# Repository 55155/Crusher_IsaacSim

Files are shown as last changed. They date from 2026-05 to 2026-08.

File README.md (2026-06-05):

# Crusher_IsaacSim

**약품 분쇄기(Crusher)** 의 Isaac Sim → MuJoCo 마이그레이션 및 정제(Tablet) 형상 시뮬레이션 통합 저장소입니다.

---

## 목차

1. [프로젝트 개요](#프로젝트-개요)
2. [하드웨어 사양](#하드웨어-사양)
3. [디렉토리 구조](#디렉토리-구조)
4. [빠른 시작](#빠른-시작)
5. [GUI 실행 (tablet_sim_gui.py)](#gui-실행-tablet_sim_guipy)
6. [밀도 기반 접촉 경도 모델](#밀도-기반-접촉-경도-모델)
7. [CLI 레퍼런스](#cli-레퍼런스)
8. [변경 이력](#변경-이력)
9. [의존성 설치](#의존성-설치)
10. [주의 사항](#주의-사항)

> **✅ 2026-06-05 업데이트 (최신)** — **실제 모터 스펙(BL4281 + 1:212) 반영** 및 **준정적 조건** 구현: 환산 관성 주입으로 수치 안정성 확보, 실측 슬라이더 힘(600–650 N) 재현.  
> **✅ 2026-06-01 업데이트** — **GUI 프론트엔드** 추가 (`tablet_sim_gui.py`): 알약 무게·형상 입력 → 밀도·solref 실시간 계산, 경도 게이지 시각화, 단일/배치 시뮬 실행 원클릭 지원.  
> **✅ 2026-05-29 업데이트** — **밀도 기반 접촉 경도 모델** 추가 (`--density` / `--mass`): Hertzian Contact Theory를 기반으로 알약 밀도 → solref 시정수 τ 자동 계산.  
> → [하드웨어 사양 바로가기](#하드웨어-사양) | [GUI 실행 바로가기](#gui-실행-tablet_sim_guipy) | [밀도 기반 접촉 경도 상세 설명](#밀도-기반-접촉-경도-모델)

---

## 프로젝트 개요

| 구성 요소 | 설명 |
|---|---|
| **Crusher_IsaacSim_description** | ROS URDF + Isaac Sim USD 원본 기술 파일 |
| **MuJoCo_PlayGround** | Crusher 모델을 MuJoCo(MJCF)로 변환·시뮬레이션 |
| **tablets_stl** | 경구정(Tablet) 형상 파라미터 기반 STL 생성·시각화·충돌 분해 |

---

## 하드웨어 사양

### 구동 모터 (Motor 1 — Crusher 크랭크)

| 항목 | 사양 |
|---|---|
| 모터 모델 | **BL4281** (BLDC) |
| 정격 토크 | 0.185 N·m |
| 무부하 속도 | 5,800 RPM |
| 로터 관성 | 72 g·cm²  (= 7.2 × 10⁻⁶ kg·m²) |
| 감속기 감속비 | **1 : 212** |
| 크랭크 출력 stall 토크 | ≈ **12.5 N·m**  (효율 ~32%) |
| 크랭크 무부하 속도 | ≈ **27.4 RPM**  (= 2.87 rad/s) |
| 크랭크 환산 관성 J_refl | **0.324 kg·m²**  (= J_motor × 212²) |

> 고감속비 감속기는 역구동 차단(self-locking) 특성이 있어 슬라이더에 부하가 걸려도 크랭크 위치가 유지됩니다.

---

### 크랭크-슬라이더 기구

| 항목 | 값 |
|---|----|
| 크랭크 반경 `r` | **20 mm** |
| 커넥팅 로드 길이 `L` | **80 mm** |
| 운전 속도 | 8 RPM |
| 슬라이더 최대 힘 (실측) | **600 – 650 N** |

슬라이더 힘 공식 (크랭크 각도 θ 기준):

```
F_slider = τ_crank / (r × sin θ)

θ = 90°  →  F = 12.5 / 0.02       = 625 N   ← 실측값과 일치 ✓
θ = 60°  →  F = 12.5 / 0.01732    = 722 N
θ = 30°  →  F = 12.5 / 0.01       = 1250 N  ← TDP 근처 증폭
```

---

### 시뮬레이션 모터 파라미터 (`crusher_velocity_ctrl.py`)

| 파라미터 | 값 | 의미 |
|---|----|---|
| `MOTOR_STALL_TORQ` | `0.185` N·m | BL4281 모터 정격 토크 |
| `MOTOR_NOLOAD_RPM` | `5800` RPM | 무부하 속도 |
| `MOTOR_INERTIA_KG` | `72e-7` kg·m² | 로터 관성 |
| `GEAR_RATIO` | `212` | 감속비 |
| `CRANK_R_M` | `0.020` m | 크랭크 반경 |
| `ROD_L_M` | `0.080` m | 커넥팅 로드 길이 |
| `_TAU_STALL_CRANK` | `12.5` N·m | 크랭크 출력 stall 토크 (실측 역산) |
| `_J_REFL` | `0.3236` kg·m² | 크랭크 body 환산 관성 (J × n²) |
| `MOTOR_FORCELIM` | `12.5` N·m | velocity actuator forcerange 상한 |
| `VEL_KV_DEFAULT` | `≈ 14.9` N·m·s/rad | actuator 게인 (= τ_stall / ω_target) |

**준정적 안정 조건 검증:**

```
안정 지수 = kv × dt / J_eff

환산관성 미적용:  14.9 × 0.002 / 4.2e-5 ≈ 710  >> 2  →  수치 발산 ✗
환산관성 적용:    14.9 × 0.002 / 0.324  ≈ 0.09 << 2  →  안정 ✓
```

환산 관성은 `_build_model()` 내에서 `L4_Shaft_1` body의 `diaginertia`에 `_J_REFL`을 더하는 방식으로 주입됩니다.

---

## 디렉토리 구조

```
Crusher_IsaacSim/
│
├── README.md                          ← 이 파일
├── requirements.txt                   ← Python 의존성 목록
├── .gitignore                         ← STL 바이너리 제외 설정
│
├── Crusher_IsaacSim_description/      ← ROS 패키지 원본
│   ├── urdf/                          ← URDF / xacro / USD 파일
│   ├── meshes/                        ← 부품별 STL 메시
│   └── Code/                          ← 보조 스크립트 (질량/관성 검사, 재질 등)
│
├── CODES/                             ← 초기 Isaac Sim 디버그 스크립트 모음
│
├── 20260505/ ~ 20260513/              ← 날짜별 Isaac Sim 작업 스크립트
│
├── MuJoCo_PlayGround/                 ← MuJoCo 시뮬레이션 작업 공간
│   ├── MJCF/
│   │   ├── Crusher_IsaacSim.xml       ← 기본 MJCF (색상 없음)
│   │   ├── Crusher_IsaacSim_colored.xml  ← 색상 + Ground + 폐루프 제약 완성본
│   │   ├── Ground.stl                 ← 바닥 메시
│   │   └── L*.stl / base_link.stl    ← 부품 메시 (42개)
│   │
│   ├── 20260514/  view_mjcf.py        ← 초기 MJCF 로더
│   ├── 20260515/  open_crusher.py     ← 기본 XML 뷰어 (경고 억제 포함)
│   ├── 20260518/                      ← 색상 파이프라인 스크립트
│   │   ├── apply_csv_to_mjcf.py       ← mesh_colors.csv → MJCF material 적용
│   │   ├── extract_materials.py       ← USD에서 재질 추출
│   │   ├── make_mesh_csv.py           ← 메시-색상 CSV 생성
│   │   └── fusion360/                 ← Fusion 360 appearances.json 기반 적용
│   │
│   ├── 20260520/
│   │   └── open_crusher_colored.py   ← ★ 색상+Ground XML Python 뷰어 (신규)
│   │
│   ├── 20260527/
│   │   └── crusher_tablet_sim.py     ← ★ Crusher + Tablet 통합 시뮬레이션 (2-Phase)
│   │
│   ├── mujoco.bat                     ← ★ 더블클릭으로 뷰어 실행 (상대경로 수정)
│   └── convert_urdf_to_mjcf.py        ← URDF → MJCF 변환기
│
└── tablets_stl/                       ← 정제 형상 도구 모음
    ├── stl/
    │   ├── _tablet_index.csv          ← 1000개 정제 파라미터 메타데이터
    │   └── tablet_R*.stl              ← 생성된 STL 파일 (git 제외)
    │
    └── Codes/
        ├── viewer_desktop.py          ← ★ PyVista 3-슬라이더 형상 뷰어 + MuJoCo 연동
        ├── launch_mujoco.py           ← ★ STL → MuJoCo 물리 시뮬레이션 런처
        ├── collision_viewer.py        ← ★ 볼록 분해 4-모드 충돌 뷰어
        ├── tablet_generator.py        ← Fusion 360 AddIn (로컬 실행 불가, 참조용)
        ├── viewer.html                ← 웹 기반 STL 브라우저
        ├── start_viewer.bat           ← viewer_desktop.py 실행 배치
        ├── run_collision_viewer.bat   ← collision_viewer.py 실행 배치
        └── install_and_run.bat        ← 의존성 설치 + 뷰어 실행 배치
```

---

## 빠른 시작

### 1. Crusher MuJoCo 뷰어 실행

```bash
# 방법 A — 더블클릭 (권장)
MuJoCo_PlayGround/mujoco.bat

# 방법 B — Python 스크립트
conda activate isaac_sim
python MuJoCo_PlayGround/20260520/open_crusher_colored.py
```

> `mujoco.bat`은 `.py` 파일을 경유하지 않고 `python -m mujoco.viewer --mjcf` 명령으로  
> 설치된 MuJoCo 패키지의 CLI 뷰어를 **직접** 실행합니다.

### 2. 정제 형상 뷰어 실행

```bash
conda activate isaac_sim
python tablets_stl/Codes/viewer_desktop.py
```

- 슬라이더로 `R` / `AR` / `CV` 파라미터 조정 → 형상 실시간 미리보기
- **[MuJoCo에서 열기]** 버튼 → 선택한 STL을 별도 창에서 물리 시뮬레이션

### 3. 충돌 메시 분해 뷰어 실행

```bash
conda activate isaac_sim
python tablets_stl/Codes/collision_viewer.py
```

- 4가지 보기 모드: 원본 메시 / 볼록 껍질 / 겹침 보기 / 면 법선
- 거친(8) / 표준(16) / 정밀(32) / 최정밀(64) hull 프리셋

### 5. Crusher + Tablet 통합 시뮬레이션 실행

```bash
conda activate isaac_sim

# 기본 실행 (밀도 1200 kg/m³ 기본값)
python MuJoCo_PlayGround/20260527/crusher_tablet_sim.py <tablet.stl>

# 밀도 직접 지정 (경질 알약)
python MuJoCo_PlayGround/20260527/crusher_tablet_sim.py <tablet.stl> --density 1500

# 실측 질량으로 밀도 자동 계산
python MuJoCo_PlayGround/20260527/crusher_tablet_sim.py <tablet.stl> --mass 320

# 파일 선택 다이얼로그로 실행
python MuJoCo_PlayGround/20260527/crusher_tablet_sim.py
```

#### 배치 시뮬레이션 실행

```bash
# 순차 실행 (기본 밀도)
python MuJoCo_PlayGround/20260527/batch_tablet_sim.py

# 병렬 실행 + 경질 알약 설정
python MuJoCo_PlayGround/20260527/batch_tablet_sim.py --parallel --workers 8 --density 1500

# 빠른 테스트 (10개, plot 저장)
python MuJoCo_PlayGround/20260527/batch_tablet_sim.py --limit 10 --save-plots --density 1200
```

#### 동작 방식

| 단계 | 내용 |
|---|---|
| **Phase 1** (뷰어 없음, 500 스텝) | `lock_crank` equality 활성 (−90° 고정) → Crusher 메커니즘 안정화 |
| **Phase 2 — 대기** (0 ~ 3 s) | 뷰어 오픈, 모터 OFF. 알약은 mocap body로 충돌판 벽면에 고정 |
| **Phase 2 — 압축** (3 s ~) | `lock_crank` 해제 → Motor CCW −0.5 N·m 구동 → 슬라이더 전진, 법선 반력 측정 |
| **Phase 2 — 역전** (stall 감지) | 크랭크 각속도 \|ω\| < 0.05 rad/s 가 STALL_TIME_S(2.0s) 연속 → 방향 전환 (CCW↔CW 반복) |

#### 핵심 구조

- **XML 파일 없음** — `Crusher_IsaacSim_colored.xml` 을 메모리에서 파싱, Tablet body 노드를 동적 삽입 후 `MjModel.from_xml_string()` 으로 직접 로드
- **알약 고정 방식 — mocap body** — `mocap="true"` 선언으로 MuJoCo가 알약을 불가침 강체 벽으로 인식. `data.mocap_pos / mocap_quat` 으로 위치·자세 제어. 관통 없음
- **접촉력 측정** — `data.contact` + `mj_contactForce()` → contact frame → world frame 변환. 알약에 작용하는 법선 반력(F_Y) 수집
- **크랭크 제어** — `lock_crank` equality (polycoef=−π/2) 런타임 해제 (`data.eq_active`), **moving-window stall 감지** 기반 양방향 자동 역전
- **알약 자세** — X축 90° + Y축 90° 합성 쿼터니언 `[0.5, 0.5, 0.5, −0.5]` → 장축이 수직(world-Z) 방향
- **실시간 플롯** — `plt.ion()` 기반 실시간 F_Y 창이 시뮬레이터와 동시 업데이트 (20 step 마다)
- **출력** — 위치·힘·임펄스·각속도 그래프 5종을 PNG로 저장

#### 알약 배치 좌표 (MuJoCo world frame)

| 축 | 값 | 의미 |
|----|----|---|
| X | −47.879 mm | 충돌판 중심 정렬 |
| Y | 336.199 mm | 충돌판(back wall) 면에 밀착 |
| Z | 50.108 mm | 수직 높이 |

---

## GUI 실행 (tablet_sim_gui.py)

> 커맨드라인 없이 마우스로 모든 파라미터를 입력하고 시뮬레이션을 실행할 수 있는 tkinter 기반 GUI입니다.

### 실행

```bash
conda activate isaac_sim
python MuJoCo_PlayGround/20260527/tablet_sim_gui.py

# STL 파일을 미리 지정하고 열기
python MuJoCo_PlayGround/20260527/tablet_sim_gui.py --stl tablets_stl/stl/tablet_R8.0_AR0.80_CV0.25.stl
```

### GUI 화면 구성

```
┌────────────────────────────────────────────────────────────────┐
│  ⚗ Crusher Tablet Simulator  —  밀도 기반 접촉 경도 자동 계산  │
├──────────────────────────────┬─────────────────────────────────┤
│  📋 알약 물성 입력            │  📊 계산 결과 (실시간)           │
│                              │                                 │
│  ○ 무게(mg) 입력             │  추정 부피   [ 320.5 ] mm³      │
│  ● 밀도(kg/m³) 직접 입력     │  추정 밀도   [  1200 ] kg/m³    │
│                              │  solref τ   [ 0.0080] s        │
│  무게    [ 500  ] mg         │  solimp d   [ 0.991 ]          │
│  밀도    [1200  ] kg/m³      │                                 │
│                              │  ─────────────────────────      │
│  반지름 R [ 8.0 ] mm         │  경도: ████████░░  Hard 65%    │
│  종횡비 AR[ 0.80]            │                                 │
│  왕관비 CV[ 0.25]            │  밀도→τ 참조표                  │
│                              │   900 → 0.0200  연질            │
│  STL 파일 [___path___] [📂]  │  1200 → 0.0080  기본값 ◀현재   │
│                              │  1800 → 0.0020  경질            │
├──────────────────────────────┴─────────────────────────────────┤
│  🚀 단일 시뮬레이션 │  📦 배치 시뮬레이션                       │
│  [☐ 그래프 저장]  [  ▶ 시뮬레이션 실행  ]                      │
├────────────────────────────────────────────────────────────────┤
│  📟 출력                                                        │
│  $ python crusher_tablet_sim.py tablet.stl --density 1200      │
│  ◆ Phase 1: 500 스텝 안정화...                                  │
│  ✔ Phase 1 완료                                                 │
└────────────────────────────────────────────────────────────────┘
```

### 주요 기능

| 기능 | 설명 |
|---|---|
| **입력 모드 토글** | 무게(mg) 입력 ↔ 밀도(kg/m³) 직접 입력 선택 |
| **실시간 계산** | 숫자 입력 즉시 → 부피·밀도·τ·solimp 자동 갱신 |
| **경도 게이지** | Soft(녹) → Medium(노) → Hard(주) → Very Hard(빨) 색상 표시 |
| **참조 테이블** | 현재 밀도에 가장 가까운 행 자동 하이라이트 |
| **콘솔 출력** | 서브프로세스 stdout 실시간 표시 (오류=빨강, 완료=녹색) |
| **단일 탭** | STL + 밀도 → `crusher_tablet_sim.py` 실행 |
| **배치 탭** | STL 폴더 전체 + 병렬/순차 선택 → `batch_tablet_sim.py` 실행 |

### 입력 모드별 동작

**무게 입력 모드** (`무게(mg) 입력` 선택)
- 무게(mg) + 형상 파라미터(R, AR, CV) → 부피 추정 → 밀도 자동 계산
- 측정된 실측 질량이 있을 때 사용
- 파일명에 `R`, `AR`, `CV` 파라미터가 포함된 STL과 연동

**밀도 직접 입력 모드** (`밀도(kg/m³) 직접 입력` 선택)
- 밀도(kg/m³)를 직접 입력 → τ 즉시 계산
- 배치 시뮬레이션에서 동일 밀도를 전체 적용할 때 사용
- 참고: 연질 ≈ 900, 일반 ≈ 1200, 경질 ≈ 1800 (kg/m³)

---

## CLI 레퍼런스

### `crusher_tablet_sim.py` — 단일 알약 인터랙티브 시뮬레이션

```
python MuJoCo_PlayGround/20260527/crusher_tablet_sim.py [STL] [옵션]
```

| 인자 | 타입 | 기본값 | 설명 |
|---|---|---|---|
| `stl` | `str` (위치 인자) | 없음 → 파일 다이얼로그 | Tablet STL 파일 경로 |
| `--density KG_M3` | `float` | `1200.0` | 알약 밀도 \[kg/m³\] → solref τ 자동 계산 |
| `--mass MG` | `float` | — | 실측 질량 \[mg\] → 형상 파라미터로 밀도 자동 계산 |

> `--density`와 `--mass`는 **상호 배타**입니다. 둘 다 생략하면 기본 밀도 1200 kg/m³ 적용.

#### 사용 예시

```bash
# 1. STL 경로 직접 지정 (기본 밀도)
python MuJoCo_PlayGround/20260527/crusher_tablet_sim.py \
    tablets_stl/stl/tablet_R6.0_AR1.50_CV0.20.stl

# 2. 밀도 직접 지정 — 경질 알약 (탄산칼슘 계열)
python MuJoCo_PlayGround/20260527/crusher_tablet_sim.py \
    tablets_stl/stl/tablet_R6.0_AR1.50_CV0.20.stl \
    --density 1600

# 3. 실측 질량으로 밀도 자동 계산 — 320 mg 알약
python MuJoCo_PlayGround/20260527/crusher_tablet_sim.py \
    tablets_stl/stl/tablet_R6.0_AR1.50_CV0.20.stl \
    --mass 320

# 4. STL 생략 → GUI 파일 선택 다이얼로그 열림
python MuJoCo_PlayGround/20260527/crusher_tablet_sim.py
python MuJoCo_PlayGround/20260527/crusher_tablet_sim.py --density 1400
```

#### 출력 파일 (자동 저장)

```
MuJoCo_PlayGround/Sim_result/
├── csv/
│   └── {stem}__{YYYYMMDD_HHMMSS}.csv          ← 반력 프로파일 + 메타데이터
└── plot/
    ├── {stem}__{ts}__realtime_force.png        ← 실시간 F_Y 스냅샷
    ├── {stem}__{ts}__position.png              ← Slider/Tablet Y + Gap
    ├── {stem}__{ts}__force_magnitude.png       ← F_Y + 누적 임펄스
    ├── {stem}__{ts}__force_components.png      ← F_X / F_Y / F_Z
    └── {stem}__{ts}__crank_velocity.png        ← 크랭크 각속도 ω
```

---

### `batch_tablet_sim.py` — 다수 알약 헤드리스 배치 시뮬레이션

```
python MuJoCo_PlayGround/20260527/batch_tablet_sim.py [옵션]
```

| 인자 | 타입 | 기본값 | 설명 |
|---|---|---|---|
| `--stl-dir PATH` | `str` | `tablets_stl/stl` | STL 파일 디렉토리 |
| `--duration SEC` | `float` | `10.0` | 정제 1개당 시뮬레이션 시간 \[s\] |
| `--density KG_M3` | `float` | `1200.0` | 알약 밀도 \[kg/m³\] → 전체 배치에 일괄 적용 |
| `--parallel` | flag | `False` | `multiprocessing.Pool` 병렬 실행 활성화 |
| `--workers N` | `int` | `os.cpu_count()` | 병렬 워커 수 (`--parallel` 사용 시) |
| `--save-plots` | flag | `False` | 정제별 개별 플롯 PNG 저장 (느림, 디스크 사용 많음) |
| `--limit N` | `int` | 없음 (전체) | 처리할 STL 수 제한 (테스트·디버그용) |

#### 사용 예시

```bash
# 1. 기본 순차 실행 — 전체 STL, 10s/tablet, 기본 밀도
python MuJoCo_PlayGround/20260527/batch_tablet_sim.py

# 2. 병렬 실행 — 8 워커, 경질 알약
python MuJoCo_PlayGround/20260527/batch_tablet_sim.py \
    --parallel --workers 8 \
    --density 1500

# 3. 긴 시뮬레이션 — 30s/tablet, 연질 알약
python MuJoCo_PlayGround/20260527/batch_tablet_sim.py \
    --duration 30 \
    --density 950

# 4. 빠른 테스트 — 10개만, plot 저장
python MuJoCo_PlayGround/20260527/batch_tablet_sim.py \
    --limit 10 --save-plots \
    --density 1200

# 5. 커스텀 STL 디렉토리
python MuJoCo_PlayGround/20260527/batch_tablet_sim.py \
    --stl-dir /path/to/custom_stl \
    --parallel --workers 4 \
    --density 1300
```

#### 출력 파일 (자동 저장)

```
MuJoCo_PlayGround/Sim_result/
├── csv/
│   ├── {YYYYMMDD_HHMMSS}/
│   │   ├── tablet_R6.0_AR1.50_CV0.20.csv      ← 개별 반력 프로파일
│   │   └── ...                                 ← (STL 1개당 CSV 1개)
│   └── summary__{YYYYMMDD_HHMMSS}.csv          ← 배치 요약 (행=1정제)
└── plot/
    ├── {YYYYMMDD_HHMMSS}/
    │   ├── tablet_R6.0_AR1.50_CV0.20__force.png ← 개별 플롯 (--save-plots 시)
    │   └── ...
    └── summary__{YYYYMMDD_HHMMSS}.png           ← 4패널 요약 산포도
```

#### summary CSV 컬럼

| 컬럼 | 설명 |
|---|---|
| `stem` | STL 파일명 (확장자 제외) |
| `R_mm`, `AR`, `CV` | 형상 파라미터 |
| `density_kg_m3` | 사용된 밀도 |
| `solref_tau_s` | 계산된 solref τ |
| `F_Y_max_N` | 최대 법선 반력 \[N\] |
| `F_Y_min_N` | 최소 법선 반력 \[N\] |
| `F_mag_max_N` | 최대 합력 크기 \[N\] |
| `Impulse_J_Y_Ns` | 누적 임펄스 J_Y \[N·s\] |
| `first_contact_s` | 첫 접촉 발생 시각 \[s\] |
| `direction_changes` | 크랭크 방향 전환 횟수 |
| `n_steps` | 수집된 스텝 수 |
| `wall_time_s` | 실제 소요 시간 \[s\] |
| `error` | 오류 메시지 (정상 시 공백) |

---

### 주요 상수 (코드 상단에서 직접 수정)

아래 상수는 CLI 인자 없이 코드에서 직접 조정합니다.

#### `crusher_tablet_sim.py`

| 상수 | 기본값 | 설명 |
|---|---|---|
| `SIM_DURATION` | `30.0` s | Phase 2 측정 시간 |
| `MOTOR_CTRL` | `-0.5` N·m | 크랭크 모터 토크 (음수=CCW) |
| `MOTOR_DELAY` | `3.0` s | 모터 구동 지연 시간 |
| `STALL_TIME_S` | `2.0` s | stall 판정 유지 시간 ("지긋이 누르는" 시간) |
| `STALL_VEL_THR` | `0.05` rad/s | stall 판정 속도 임계값 |
| `RT_PLOT_INTERVAL` | `20` steps | 실시간 플롯 갱신 주기 |
| `DENSITY_REF_SOFT` | `900` kg/m³ | solref 매핑 연질 기준점 |
| `DENSITY_REF_HARD` | `1800` kg/m³ | solref 매핑 경질 기준점 |
| `SOLREF_TAU_SOFT` | `0.020` s | 연질 기준 τ (MuJoCo 기본값) |
| `SOLREF_TAU_HARD` | `0.002` s | 경질 기준 τ (실용적 최솟값) |

#### `batch_tablet_sim.py` (추가)

| 상수 | 기본값 | 설명 |
|---|---|---|
| `PHASE1_STEPS` | `500` steps | 메커니즘 안정화 스텝 수 |

---

## 밀도 기반 접촉 경도 모델

### 개요

같은 형상(Shape)의 알약이라도 **밀도(density)**가 높을수록 파쇄가 어렵습니다.  
밀도는 실측 무게와 형상(부피)으로 추정할 수 있으며, 이를 MuJoCo 접촉 파라미터(`solref`)에 반영합니다.

### 이론적 근거 (Hertzian Contact Theory)

```
제약공학 사실:
  압착 압력↑  →  밀도(ρ)↑  →  Young's modulus(E)↑  →  경도↑

Hertzian Contact:
  접촉 강성  K_contact  ∝  E*  (등가 탄성계수)
  경험적 관계: E  ∝  ρⁿ   (n ≈ 2~3)

MuJoCo solref 연결:
  K_mujoco  ∝  1/τ²   (τ = solref 시정수)
  K ∝ ρⁿ, K ∝ 1/τ²   →   τ  ∝  ρ^(-n/2)

결론: 밀도 높음 → τ 작음 → 접촉 강성 높음 → 관통 감소
```

### 매핑 함수

두 기준점을 지정하면 **power-law**로 보간합니다:

```
τ(ρ) = τ_soft × (ρ_soft / ρ)^α

        log(τ_hard / τ_soft)
α  = ─────────────────────────  ≈ −3.32
        log(ρ_hard / ρ_soft)
```

| 밀도 (kg/m³) | τ (s) | 상대 강성 (1/τ²) | 대표 알약 |
|---|---|---|---|
| 900 | 0.0200 | 1× | 연질 (저압착 포도당) |
| 1100 | 0.0096 | 4.3× | 표준 하한 |
| **1200** | **0.0080** | **6.3×** | ← 기본값 |
| 1400 | 0.0053 | 14× | 표준 경질 |
| 1600 | 0.0033 | 37× | 고압착 |
| 1800 | 0.0020 | 100× | 초경질 (탄산칼슘) |

### 부피 추정 및 밀도 계산

알약 실측 질량(mg)만 알면 형상 파라미터로 밀도를 자동 계산합니다:

```
V_ellipsoid = (4/3)π × (R×AR) × R × (th/2)
V_biconvex  = V_ellipsoid × 0.82   (biconvex 보정계수)

ρ = mass / V_biconvex
```

```bash
# 실측 질량 320mg → 밀도 자동 계산 → τ 자동 설정
python crusher_tablet_sim.py tablet_R6.0_AR1.50_CV0.20.stl --mass 320
```

### 구현 위치

| 함수 | 설명 |
|---|---|
| `estimate_tablet_volume_mm3(R_mm, AR, CV)` | 형상 파라미터 → 부피 [mm³] 추정 |
| `mass_to_density(mass_mg, R_mm, AR, CV)` | 질량 + 형상 → 밀도 [kg/m³] |
| `density_to_solref_tau(density_kg_m3)` | 밀도 → solref τ [s] (power-law) |
| `_build_model(..., density_kg_m3)` | geom에 `density`, `solref`, `solimp` 적용 |

### 조정 가능한 기준점 (코드 상단 상수)

```python
DENSITY_REF_SOFT  = 900.0    # kg/m³  연질 기준점
DENSITY_REF_HARD  = 1800.0   # kg/m³  경질 기준점
SOLREF_TAU_SOFT   = 0.020    # s      연질 τ (MuJoCo 기본값)
SOLREF_TAU_HARD   = 0.002    # s      경질 τ (실용적 최솟값)
DENSITY_DEFAULT   = 1200.0   # kg/m³  미지정 시 기본값
BICONVEX_VOL_FACTOR = 0.82   # biconvex 부피 보정계수
```

### CSV 출력 컬럼 (신규 추가)

결과 CSV 메타데이터에 밀도 관련 정보가 자동 기록됩니다:

```
# density_kg_m3, vol_estimate_mm3, biconvex_factor
# solref_tau_s, solimp_dmax, DENSITY_REF_SOFT, DENSITY_REF_HARD
```

---

### 4. 정제 STL 생성 (Fusion 360 전용)

`tablets_stl/Codes/tablet_generator.py` 참조.  
로컬에서 직접 실행 불가 — Fusion 360 내부 AddIn으로만 사용 가능합니다.

---

## 변경 이력

### 2026-06-05 — 실제 모터 스펙 반영 및 준정적 조건 구현

#### 핵심 변경

| 항목 | 변경 전 | 변경 후 |
|---|---|---|
| **MOTOR_FORCELIM** | 120 N·m (임의값) | **12.5 N·m** (실측 역산: F=625N × r=0.02m) |
| **VEL_KV_DEFAULT** | 60 → 3 (진동 수정) | **14.9** (= τ_stall / ω_target, 물리 근거 수치) |
| **환산 관성 주입** | 없음 | `_build_model()`에서 `L4_Shaft_1`에 J×n²=**0.324 kg·m²** 추가 |
| **모터 상수 추가** | 없음 | `GEAR_RATIO`, `MOTOR_STALL_TORQ`, `MOTOR_INERTIA_KG`, `CRANK_R_M`, `ROD_L_M` |

#### 배경: 진동 원인 및 해결 과정

kv=60이었을 때 stall 토크 = 60 × 0.838 = **50 N·m** (현실 모터의 ~20배).  
접촉 순간 속도 강하 → kv × Δω 보정 토크 과다 → 속도 오버슈트 → 진동.

| 단계 | kv | MOTOR_FORCELIM | 안정 지수 kv·dt/J | 결과 |
|---|----|---|---|---|
| 초기 | 60 | 120 N·m | 710 (J≈크랭크만) | 진동 발생 |
| 1차 수정 | 3 | 3 N·m | 0.09 | 진동 해소, 힘 과소 |
| **최종** | **14.9** | **12.5 N·m** | **0.09** (환산관성 포함) | 안정 + 실측 재현 ✓ |

#### 슬라이더 힘 검증

실측 600–650 N ↔ 시뮬레이션 예측:
- τ_stall = 12.5 N·m, r = 0.02 m, θ = 90° → F = **625 N** ✓

#### 수정 파일

| 파일 | 수정 내용 |
|---|---|
| `MuJoCo_PlayGround/20260603/crusher_velocity_ctrl.py` | BL4281 스펙 상수 추가, 환산 관성 주입(`_build_model`), kv·forcelim 실측 재산정 |
| `README.md` | 하드웨어 사양 섹션 신규 추가 |

---

### 2026-05-29 (2) — 밀도 기반 접촉 경도 모델 (solref 자동 계산)

#### 핵심 변경

| 항목 | 변경 전 | 변경 후 |
|---|---|---|
| **tablet geom solref** | 미지정 (MuJoCo 기본값 τ=0.02s) | **밀도 → τ 자동 계산** (power-law 보간) |
| **tablet geom density** | 1200 kg/m³ 하드코딩 | `--density` 또는 `--mass` 인자로 동적 설정 |
| **_build_model 시그니처** | `(stl_path, R_mm, half_th)` | `(stl_path, R_mm, half_th, density_kg_m3)` |
| **CLI 인자** | 없음 | `--density KG_M3` / `--mass MG` (상호 배타) |
| **CSV 메타데이터** | 없음 | `density_kg_m3`, `solref_tau_s`, `solimp_dmax`, `vol_estimate_mm3` 추가 |
| **batch_tablet_sim.py** | 동일 | `--density` 인자 + task tuple에 밀도 포함 |

#### 신규 함수

| 함수 | 위치 | 설명 |
|---|---|---|
| `estimate_tablet_volume_mm3(R, AR, CV)` | 두 파일 공통 | 형상 파라미터 → biconvex 부피 [mm³] |
| `mass_to_density(mass_mg, R, AR, CV)` | 두 파일 공통 | 질량(mg) + 형상 → 밀도 [kg/m³] |
| `density_to_solref_tau(density_kg_m3)` | 두 파일 공통 | 밀도 → solref τ [s] (power-law) |

#### 이론

```
Hertzian Contact: E ∝ ρⁿ  →  K ∝ 1/τ²  →  τ ∝ ρ^(-n/2)
α = log(τ_hard/τ_soft) / log(ρ_hard/ρ_soft) ≈ −3.32
```

#### 수정 파일

| 파일 | 변경 내용 |
|---|---|
| `MuJoCo_PlayGround/20260527/crusher_tablet_sim.py` | v7 — 밀도 기반 solref, --density/--mass CLI |
| `MuJoCo_PlayGround/20260527/batch_tablet_sim.py` | v2 — 동일 로직, --density CLI, task tuple 확장 |
| `README.md` | 밀도 기반 접촉 경도 모델 섹션 신규 추가 |

---

### 2026-05-29 (1) — Moving-window 역전 알고리즘 + 실시간 반력 플롯

#### 핵심 변경

| 항목 | 변경 전 | 변경 후 |
|---|---|---|
| **크랭크 역전 방식** | 접촉력 임계(`\|F_Y\| > 5 N`) → CCW→CW 단방향, 복귀 없음 | **Moving-window stall 감지** — 양방향 (CCW↔CW 반복) |
| **역전 트리거 조건** | 접촉력 크기 기반 | 크랭크 각속도 `\|ω\| < 0.05 rad/s` 30 step 연속 유지 |
| **실시간 플롯** | 없음 (시뮬 종료 후 정적 PNG만) | `plt.ion()` 기반 F_Y 실시간 창 (20 step 간격 갱신) |
| **출력 그래프** | 3종 (위치, 힘, XYZ 성분) | **5종** — 위치, 힘+임펄스, XYZ 성분, **실시간 스냅샷**, **크랭크 각속도** |
| **콘솔 출력** | 위치·힘·접촉 수 | 위치·힘·각속도·현재 방향(`[CCW]`/`[CW]`) |

#### 상세 내용

**① Moving-window stall 감지 기반 양방향 역전**
```
STALL_WINDOW  = 30      # 연속 판정 스텝 수 (0.002 s × 30 = 0.06 s)
STALL_VEL_THR = 0.05    # 크랭크 속도 임계 [rad/s]
```
- `deque(maxlen=30)` — 최신 30 스텝의 `|ω| < threshold` 불리언 기록
- `all(stall_buf)` 가 True 되는 순간 `motor_dir = -motor_dir` 전환, deque 초기화
- 부호 규칙: `data.ctrl[act_crank] = motor_dir × MOTOR_CTRL`
  - `motor_dir = +1` (CCW) → ctrl = −0.5 N·m
  - `motor_dir = −1` (CW) → ctrl = +0.5 N·m
- CCW→CW, CW→CCW 모두 자동 처리. 역전 횟수·시각 콘솔 출력 및 플롯 마커 기록

**② 실시간 법선 반력 플롯 (`plt.ion()`)**
- 시뮬레이터 뷰어와 동시에 별도 창으로 F_Y [N] 실시간 표시
- 20 step(0.04 s)마다 `line_fy.set_data()` + `ax_rt.relim()` + `flush_events()`
- 방향 전환 이벤트 수직선(axvline)을 실시간 갱신
- 시뮬 종료 후 `crusher_tablet_realtime_force.png` 로 저장

**③ 크랭크 각속도 플롯 추가 (그림 4)**
- `data.qvel[crank_vadr]` 로그를 시간 축으로 표시
- stall 임계선 `±STALL_VEL_THR` 수평선 표시
- 방향 전환 이벤트 수직선 동기화

#### 수정 파일

| 파일 | 수정 내용 |
|---|---|
| `MuJoCo_PlayGround/20260527/crusher_tablet_sim.py` | v5 — moving-window 역전, 실시간 플롯, 각속도 플롯, 다중 역전 이벤트 추적 |

---

### 2026-05-28 — 알약 물리 고정 방식 전환 및 반력 측정 파이프라인 완성

#### 핵심 변경

| 항목 | 변경 전 | 변경 후 |
|---|---|---|
| **알약 고정 방식** | freejoint + 매 스텝 qpos/qvel 덮어쓰기 (kinematic hold) | `mocap="true"` body — 관통 없는 불가침 강체 벽 |
| **접촉력 측정** | `cfrc_ext` (부정확, 유령 body 문제) | `data.contact` + `mj_contactForce()` → world frame 변환 |
| **크랭크 초기 각도** | +90° | **−90°** |
| **모터 방향** | CW (+0.5 N·m) | **CCW (−0.5 N·m)**, 3초 지연 후 구동 |
| **크랭크 역전 트리거** | gap 기반 (슬라이더 위치) → 벽 접촉 시 고착으로 동작 안 됨 | **접촉력 기반** `|F_Y| > 5 N` → 신뢰성 있는 역전 |
| **알약 자세** | X축 90° (눕힘) | X축 90° + Y축 90° 합성 → **세로(수직) 방향** |

#### 상세 내용

**① mocap body 전환 (관통 문제 해결)**
- `freejoint` 방식에서는 MuJoCo contact solver가 분리 impulse를 계산해도 매 스텝 qpos를 덮어써서 슬라이더가 알약을 관통하는 문제 발생
- `mocap="true"` body는 물리 엔진이 직접 불가침 강체로 취급 → 슬라이더가 알약을 밀어내고 알약은 고정 유지
- 위치·자세 제어: `data.mocap_pos[mocap_id]`, `data.mocap_quat[mocap_id]`

**② lock_crank equality 런타임 토글**
- `Crusher_IsaacSim_colored.xml` 의 `lock_crank` (polycoef=−1.5708, solref=−100000) 로 Phase 1에서 크랭크를 −90°에 고정
- Phase 2 시작 3초 후 `data.eq_active[eq_lock_id] = 0` 으로 해제 → 모터 CCW 구동

**③ 접촉력 기반 크랭크 역전**
- 기존 gap 기반: 슬라이더가 mocap 벽에 막히면 gap이 최솟값에 고착 → `elif gap > min + 0.5mm` 조건 영원히 불충족
- **수정**: `|F_Y| > REVERSE_F_THRESHOLD (5 N)` 초과 시점에 `ctrl = +0.5 N·m` (CW) 역전
- 역전 시각, 접촉력, gap 값을 콘솔 출력 및 플롯 마커로 기록

**④ 법선 반력 플롯 개선**
- F_Y 그래프 레이블을 "Normal Contact Force (World-Y)" 로 명확화
- 모터 ON 시각, 크랭크 역전 시각을 수직선(axvline)으로 표시
- 압축(양)/인장(음) 구간 fill_between 색 구분

**⑤ Tablet Shape Viewer 단축키 패널 추가**
- `viewer_desktop.py` 좌측 패널 하단에 PyVista 단축키 섹션 추가
- 마우스 조작 / 렌더링(`W` 와이어프레임 ★) / 카메라 / 기타 4개 섹션

#### 수정 파일

| 파일 | 수정 내용 |
|---|---|
| `MuJoCo_PlayGround/20260527/crusher_tablet_sim.py` | mocap body, lock_crank 토글, CCW 모터, 역전 로직, 법선 반력 플롯 |
| `MuJoCo_PlayGround/MJCF/Crusher_IsaacSim_colored.xml` | lock_crank polycoef −1.5708 복원 |
| `tablets_stl/Codes/viewer_desktop.py` | PyVista 단축키 패널 추가 |

---

### 2026-05-27 — Crusher + Tablet 통합 시뮬레이션 완성

#### 신규 파일

| 파일 | 내용 |
|---|---|
| `MuJoCo_PlayGround/20260527/crusher_tablet_sim.py` | Crusher XML + Tablet STL을 메모리에서 조합해 2-Phase 통합 시뮬레이션 실행. Phase 1(메커니즘 안정화) → Phase 2(알약 고정 + 접촉력 측정 + 그래프 저장) |

#### 주요 변경 사항

| 항목 | 내용 |
|---|---|
| **알약 고정 방식** | freejoint(6자유도) + 매 스텝 kinematic hold (qpos/qvel 덮어쓰기) → 알약을 공간에 고정하면서 cfrc_ext 접촉 반력 측정 가능 |
| **알약 배치** | Y 좌표를 `WALL_Y_MM`(336.199 mm)으로 설정 — 충돌판 벽면에 중심 밀착 |
| **MJCF 구성** | 별도 XML 파일 없음 — 기존 Crusher XML을 메모리에서 파싱 후 Tablet body / sensor 노드 동적 삽입 |
| **뷰어 site 구 제거** | `sitegroup` 전체 `False` — 중심부 구 형태 gizmo 비표시 |

---

### 2026-05-26 — Crank-Slider 메커니즘 진단 및 좌표계 분석

#### 핵심 발견

| 항목 | 내용 |
|---|---|
| **Equality Constraint 타입 오류** | `connect`는 위치(3-DOF)만 구속 → L7-L8 사이 회전 자유도 미구속으로 진동 발생. `weld`(위치+방향 완전 고정)로 교체 필요 |
| **Constraint Gap 원인 분석** | anchor=0.027 설정 시 L8 body와 10 mm 갭 발생 → 제약력 500 N (중력 12.7 N의 **39배**) → CCW 비정상 회전 유발 |
| **크랭크 회전축 오해** | XML `axis="0 0 1"` (body local Z) + `quat="0.5 0.5 0.5 0.5"` → 실제 world 회전축 = **[1, 0, 0] (world X)**. 중력(-Z)과 수직이므로 최대 토크 발생 |
| **MuJoCo 좌표계 변환** | `quat="0.5 0.5 0.5 0.5"` → R=`[[0,0,1],[1,0,0],[0,1,0]]` : URDF X→MuJoCo Y, URDF Y→MuJoCo Z, URDF Z→MuJoCo X |

#### 신규 파일

| 파일 | 내용 |
|---|---|
| `MuJoCo_PlayGround/20260526/coordinate_gizmo.py` | MuJoCo 월드 좌표계(XYZ 기즈모) 확인 스크립트. 뷰어 원점에 body frame 표시 |
| `MuJoCo_PlayGround/20260526/open_urdf.py` | 원본 URDF를 MuJoCo로 직접 로드해 각 body 월드 위치·joint 목록 출력 및 뷰어 실행 |

#### MJCF 수정 이력 (Crusher_IsaacSim_colored.xml)

| 수정 | 내용 |
|---|---|
| L5-L6, L6-L7 hinge damping 추가 | `damping="0.5"` — 초기 불안정 진동 억제 |
| L8 slide joint damping 추가 | `damping="5"` |
| L8_Link3_Shaft_1 body pos 수정 | Rigid32 접합 위치 = `(-0.048302, 0.236278, 0.049431)` (URDF 실측 검증 완료) |
| Equality Constraint anchor | URDF Rigid32 joint xyz=(0.037, 0, -0.005) 기준. **다음 단계: connect → weld 교체 예정** |
| 뷰어 설정 | `mjVIS_CONVEXHULL=False`, `geomgroup[3]=False` — visual mesh 전용 표시 |

---

### 2026-05-21 — macOS 호환성 수정 및 tablet_generator Fusion 360 등록

| 파일 | 변경 내용 |
|---|---|
| `tablets_stl/Codes/viewer_desktop.py` | `subprocess.CREATE_NEW_CONSOLE` (Windows 전용) → `platform.system()` 감지 후 조건부 적용으로 macOS 호환 수정 |
| `tablets_stl/stl/_tablet_index.csv` | Fusion 360 `tablet_generator` AddIn 실행으로 정제 STL 1,000개 생성 및 인덱스 갱신 |

---

### 2026-05-20 — MuJoCo 통합 완성 및 구조 정리

#### MuJoCo_PlayGround

| 파일 | 변경 내용 |
|---|---|
| `mujoco.bat` | 하드코딩된 절대경로 → `%~dp0` 기반 상대경로로 전면 수정; conda 활성화 경로도 `%USERPROFILE%` 변수로 포터블화 |
| `20260520/open_crusher_colored.py` | **신규** — `Crusher_IsaacSim_colored.xml`(Ground.stl 포함)을 Python API(`mujoco.viewer.launch`)로 여는 스크립트; `__file__` 기준 상대경로 사용 |

#### tablets_stl

| 파일 | 변경 내용 |
|---|---|
| `Codes/viewer_desktop.py` | **[MuJoCo에서 열기]** 버튼 추가; STL 로드 성공 시 활성화, `subprocess.Popen`으로 비차단 실행 |
| `Codes/launch_mujoco.py` | **신규** — 선택된 STL을 메모리 내 MJCF로 변환(`from_xml_string + assets`), 물리 파라미터(밀도 1200 kg/m³, 마찰 0.5) 설정 후 뷰어 실행 |
| `Codes/launch_mujoco.py` | **버그 수정** — `_print_params()` 정규식이 파일명의 `.stl` 확장자까지 캡처하여 `float('0.20.')` 오류 발생 → `os.path.splitext()` 로 확장자 제거 후 정규식 적용 |
| `Codes/collision_viewer.py` | **신규** — 볼록 분해(CoACD → VHACD → single hull fallback) 독립 뷰어; 4-모드 시각화 |

#### 저장소 공통

| 파일 | 변경 내용 |
|---|---|
| `requirements.txt` | **신규** — 그룹별 의존성 정리 (수치연산 / 3D시각화 / 메시처리 / MuJoCo / JAX / 이미지처리); 비pip 패키지(Isaac Sim, Fusion 360, Blender) 설치 안내 주석 포함 |
| `.gitignore` | **신규** — `tablets_stl/stl/*.stl`, `tablets_stl/collision/*.stl` 바이너리 제외; Python 캐시 제외 |

---

### 2026-05-18 — Crusher 색상 파이프라인 완성

| 변경 내용 |
|-----------|
| Fusion 360 appearance JSON 추출 스크립트 (`extract_appearance.py`) |
| `mesh_colors.csv` 기반 MJCF material 자동 적용 (`apply_csv_to_mjcf.py`) — RGB 0-255 → 0-1 변환, 조명 3개 자동 추가 |
| `Crusher_IsaacSim_colored.xml` 완성 — 색상·조명·Ground.stl·Crank-slider 폐루프 equality constraint·Motor1_crank 액추에이터·L1_Slider_jig 프리즈매틱 조인트 포함 |

---

### 2026-05-15 — MuJoCo 초기 마이그레이션

| 변경 내용 |
|-----------|
| URDF → MJCF 변환 (`convert_urdf_to_mjcf.py`) |
| 기본 뷰어 스크립트 `20260515/open_crusher.py` (MuJoCo UserWarning 억제) |

---

### 2026-05-05 ~ 2026-05-13 — Isaac Sim 디버그 및 관절 설정

| 작업 |
|------|
| 구동부 관절(Drive, Prismatic, Mimic) 설정 및 진단 스크립트 |
| Rack-and-Pinion 기어 연결 디버그 |
| CoACD 충돌 메시 최적화 |
| 질량/관성 텐서 검사 및 수정 |

---

## 의존성 설치

```bash
conda activate isaac_sim
pip install -r requirements.txt
```

> ⚠️ 아래 패키지는 pip으로 설치되지 않습니다.
> - **Isaac Sim** (`omni.*`, `carb`, `pxr`) — NVIDIA Isaac Sim 설치 시 번들 제공
> - **Fusion 360 API** (`adsk`) — Autodesk Fusion 360 내부 실행 전용
> - **Blender Python** (`bpy`) — Blender 내부 실행 전용

---

## 주의 사항

- **STL 바이너리** (`tablets_stl/stl/*.stl`) 는 `.gitignore`에 의해 Git에서 제외됩니다.  
  STL 파일은 Fusion 360 AddIn(`tablet_generator.py`)으로 로컬에서 생성하세요.
- `tablet_generator.py`는 `adsk` 모듈 의존성으로 인해 **Fusion 360 외부에서 실행 불가**합니다.  
  파일 내 주석의 설치 경로 안내를 따르세요.
- MuJoCo STL 단위는 **mm → m 자동 변환** (scale `0.001`)이 적용됩니다.  
  Fusion 360 기본 STL 내보내기 단위가 mm이기 때문입니다.

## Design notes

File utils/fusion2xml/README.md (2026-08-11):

# fusion2xml — Fusion 360 → MuJoCo MJCF

Fusion 디자인을 MuJoCo `.xml`(MJCF)로 바로 내보내는 Add-In.

## 왜 fusion2urdf 로는 안 되나

URDF 에는 equality constraint 가 없다. 링크마다 부모가 **정확히 하나**인 트리만
표현할 수 있어서, 커넥팅로드-크랭크 같은 폐루프 기구는 원리적으로 담기지 않는다.
fusion2urdf 는 루프를 닫는 조인트를 URDF 에서 빼 사이드카 파일
(`*.constraints.mjcf`)에 좌표만 적어 두고, 사람이 MJCF 로 손으로 옮겨야 했다.

fusion2xml 은 처음부터 MJCF 를 쓴다. `<body>` 중첩은 여전히 트리지만, 루프를 닫는
조인트는 **같은 XML 안의 `<equality>`** 로 닫히므로 옮길 게 없다.

## ⚠ 내보내기 전에 — 모든 조인트를 0으로 되돌릴 것

**Fusion 조인트를 드래그해 둔 자세 그대로 내보내면 조인트 원점이 그 자세로
굳어 들어간다.** 메시는 별개로 배치되므로 기구 치수가 조용히 틀어진다.

실제로 겪은 사례(`docs/DigitalTwin.md` §12-3): 크랭크를 사점(180°)에 둔 채
내보냈더니 크랭크핀과 equality anchor가 **둘 다 정확히 35 mm(= 2×편심)**
밀렸다. 커넥팅로드의 유효 길이가 60 mm → 25 mm로 뭉개져 로드 요동폭이
33.9° → 89.1°가 됐고, 풀리와 로드가 반대로 도는 것처럼 보였다.

**행정(stroke) = 2 × 편심이라 편심 방향이 반대여도 행정은 같게 나온다.**
행정만 확인하면 정상으로 보이므로, 검증할 때는 **로드 길이(핀 사이 거리)를
반드시 같이 확인**할 것.

리밋도 같은 문제를 받는다 — MJCF의 `qpos=0`은 내보낸 시점의 자세이므로,
조인트 zero가 아닌 자세로 내보내면 리밋 값이 통째로 그만큼 밀린다.

## 설치

폴더 통째로 Fusion 의 Add-Ins 폴더에 넣거나, `Utilities > ADD-INS >
Scripts and Add-Ins > Add-Ins` 탭에서 이 폴더를 추가하고 Run.

버튼: `Utilities` 탭 > `ADD-INS` 패널 > **Fusion2MJCF 내보내기**

## 어느 두 링크를 equality 로 묶을지

대화상자에서 고른다.

- **자동 감지** — 무향 그래프에서 사이클을 찾아 루프를 닫는 조인트를 자동으로
  빼서 equality 로 돌린다. Fusion 에서 루프를 이미 닫아 뒀다면 이것만으로 끝난다.
- **수동 지정** — `equality body1` / `equality body2` 드롭다운에서 두 링크를
  직접 고른다. 아직 Fusion 에서 루프를 안 닫아 뒀다면(=사이클이 없으면) 감지될
  게 없으므로 이 경로가 필요하다.
- **추가 쌍** — 여러 개를 묶으려면 `A:B:connect, C:D:weld` 형식으로 적는다.
  anchor 가 필요하면 네 번째 칸에 넣는다: `A:B:connect:0.12 0 0.09`.

### anchor 는 어디서 오나

1. 두 링크 사이에 **Fusion 조인트가 있으면 그 원점**을 쓴다. 이게 정상 경로다 —
   Fusion 에서 루프를 닫아 두면 위치가 정확히 나온다.
2. 조인트가 없으면 `anchor` 칸에 root 기준 좌표(m)를 직접 적는다. 비워 두면
   내보내기가 막힌다(조용히 틀린 위치로 나가는 것보다 낫다).

조인트가 없어 끊은 자유도를 알 수 없을 때는 **connect** 를 고른다. 예전에는
`fixed` 로 떨어져 weld 가 나왔는데, weld 는 에러 없이 로딩되고 기구학만
조용히 어긋난다(4절링크 실측: 로커암이 정답의 1/3.6 만 움직임).

### connect 냐 weld 냐

끊는 조인트의 자유도에 맞춰 자동으로 고른다.

| 끊은 조인트 | equality | 정확한가 |
|---|---|---|
| `fixed` (0 DOF) | `weld` | 정확 (6자유도 전부 구속) |
| `Ball` (회전 3) | `connect` | 정확 (병진 3만 구속) |
| `revolute` (회전 1) | `connect` | 면외 회전 2자유도가 남는다. 루프의 회전축이 전부 평행한 **평면 기구면** 트리가 그 2를 이미 막고 있어 결과적으로 정확하고, 아니면 과소구속 |
| `prismatic` | `connect` | **과대구속** — 미끄럼 방향까지 막힌다. 루프 안의 다른 조인트를 끊는 편이 낫다 |

`connect` 가 남기는 자유도는 3 Prismatic 이 아니라 **구면(볼조인트) 3회전**이다.
"칠판 위 거동"(2병진+1회전)이 필요하면 `connect` 하나로는 안 되고, 평면성이
트리 쪽에서 보장돼야 한다.

## fusion2urdf 와 공유하는 좌표 규약

- 조인트 `xyz` 는 **root 기준 절대 위치**(m).
- 링크 프레임 원점 = 그 링크를 자식으로 갖는 조인트의 위치. base_link 는 원점.
- 모든 프레임이 root 와 축정렬(회전 없음) → 프레임 간 변환이 순수 평행이동.
- STL 은 `copy_occs` 로 컴포넌트를 복제해 **root 좌표**로 내보낸다.

덕분에 MJCF 변환이 뺄셈만으로 끝난다:

```
<body pos>  = 링크원점(자신) - 링크원점(부모)
<joint pos> = "0 0 0"
<geom pos>  = -링크원점(자신)
connect anchor = anchor(root) - 링크원점(body1)
weld relpose   = 링크원점(body2) - 링크원점(body1),  회전은 단위 사원수
```

## fusion2urdf 와 다르게 처리하는 것

- **하위 컴포넌트 안의 조인트까지 훑는다.** `make_joints_dict` 는 `root.joints`
  만 봐서, Fusion 에서는 붙여놨는데 트리가 끊기는 일이 있었다. 폐루프를 닫는
  조인트가 하필 그런 위치에 있으면 루프 자체가 안 보인다.
  As-built Joint(한글 UI 의 "현재 위치에서 접합")는 다루지 않는다 — 조인트
  원점이 없어 equality anchor 를 뽑을 근거가 없다.
- **`fullinertia` 순서를 바꾼다.** URDF 는 `ixx iyy izz ixy iyz ixz`, MJCF 는
  `ixx iyy izz ixy ixz iyz` — 뒤 두 개가 뒤바뀐다. 그대로 옮기면 관성이 조용히
  틀어진다.
- **관성을 미리 검사한다.** MuJoCo 는 관성 텐서가 양정치가 아니거나 주모멘트가
  삼각부등식을 어기면 로딩을 거부한다. URDF/Gazebo 는 그냥 넘어가므로
  fusion2urdf 로는 안 드러나던 문제가 여기서 처음 터진다. 어느 링크가 문제인지
  리포트에 적고, `compiler balanceinertia="true"` 로 로딩 자체는 되게 해 둔다.
- **이름을 ASCII 로 바꾼다.** MuJoCo 는 한글이 든 메시 파일을 못 연다
  (`Error opening file 'meshes/키-30-3 v1.stl'`). 링크 이름 = 메시 이름 =
  파일명이 한 몸이라 파일명만 따로 바꿀 수 없어서, 비ASCII 를 밑줄로 바꾸고
  원본 해시 4자리를 붙여 구분한다. 바뀐 목록은 리포트에 적는다.
  **저장 경로에 한글이 있으면 그것만으로도 로딩이 막히므로** ASCII 폴더를
  골라야 한다.
- **자기충돌을 뺀다.** MuJoCo 는 부모-자식 body 쌍의 접촉을 자동으로 거르지만
  부모가 world 면 일부러 안 거른다. `fix_base` 면 `base_link` 가 world 로
  weld 되므로 여기 붙은 움직이는 링크가 전부 예외에 걸려 `base_link` 메시와
  부딪친다. 게다가 mesh 충돌 geom 은 볼록껍질이 되어 축이 지나갈 구멍까지
  메워진다. 실측(회수장치2): 초기 자세에서 접촉 40쌍, 축이 22.6mm 파묻힌 채
  시작해 토크를 걸어도 기구가 안 움직였다. 조인트/equality 로 이어진
  **weld 그룹 사이**를 `<contact><exclude>` 로 뺀다 — 부모-자식만 빼면
  축에 끼워진 베어링·와셔가 그대로 남아 효과가 없다.
- **구동할 관절을 고를 수 있다.** 폐루프 기구는 자유도가 관절 수보다 적다.
  남는 관절까지 구동하면 액추에이터가 equality 를 사이에 두고 싸워 기구가
  굳는다(4절링크 실측: 3개 다 구동 시 로커암 −0.058 rad, 크랭크만 구동 시
  −1.583 rad — 27배 차이). 비워 두면 전부 구동하되 폐루프가 있으면 경고한다.

## 출력

```
<모델명>_mjcf/
  <모델명>.xml           MuJoCo 가 바로 읽는 MJCF
  <모델명>.report.txt    equality 목록 / 경고 / 메시 내보내기 결과
  meshes/*.stl
```

```bash
python -m mujoco.viewer --mjcf=<모델명>_mjcf/<모델명>.xml
```

## 주의

- **메시를 내보내면 디자인이 바뀐다.** `copy_occs` 가 모든 컴포넌트를 복제하고
  원본 이름을 `old_component` 로 바꾼다(fusion2urdf 와 같은 방식). 저장하지 말고
  `Ctrl+Z` 로 되돌릴 것.
- 저장 경로에 한글이 있으면 MuJoCo 가 메시를 못 읽는 경우가 있다. 내보내기 후
  경고로 알려준다.

## 검증 범위

`core/Tree.py` 와 `core/Mjcf.py` 는 `adsk` 에 의존하지 않아 Fusion 밖에서 테스트
가능하다. 4절 링크 목(mock)으로 다음을 확인했다:

- 폐루프 자동 감지, 수동 지정, anchor 누락 시 차단
- 뒤집힌 조인트의 축 반전
- body pos 가 부모 상대 / geom pos 가 `-링크원점` / anchor 가 body1 로컬
- 관성 고유값·삼각부등식 검사, `fullinertia` 재배열
- **MuJoCo 실제 로딩 + 시뮬레이션**: 크랭크에만 토크를 걸었을 때 equality 가
  있는 쪽에서만 로커암까지 동력이 전달되고(2.4 rad 차이), 핀 벌어짐이
  1.8e-5 m 에 머무름
- weld 그룹 exclude 로 초기 접촉 4쌍 → 0쌍, 크랭크만 구동 시 로커암
  −1.576 rad (전부 구동하면 −0.436 rad 로 굳음)
- 조인트 없는 쌍의 자동 선택이 connect 로 나오고, 추가 쌍의 4칸 anchor 문법
  (`A:B:connect:x y z`)만으로 열린 루프가 닫힘

실제 모델(회수장치2, body 33개)로도 확인했다 — 죽은 asset 7개 제거,
weld 그룹 exclude 260쌍, 액추에이터 1개로 줄이자 접촉 40점 → 0점이 되고
구동축 ±0.05 N·m 에 크랭크-슬라이더가 대칭으로 작동한다(±0.571 rad,
슬라이더 −0.0035 m).

`core/Extract.py`, `core/Mesh.py`, 대화상자는 여전히 **Fusion 실기 미검증**
이다 — 위 검증은 모두 Fusion 밖에서 mock 과 기존 출력물로 한 것이다.

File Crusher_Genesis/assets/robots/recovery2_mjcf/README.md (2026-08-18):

# recovery2_mjcf — 회수장치2 MJCF (fusion2xml 직행 빌드)

Fusion360 → MJCF 를 URDF 경유 없이 직접 내보낸 빌드(`utils/fusion2xml`).
2026-08-12 빌드분을 그대로 가져왔다.

## 회수장치2_description 과의 관계 — **둘은 다른 자산이다**

| | `회수장치2_description/회수장치2.xml` | `recovery2_mjcf/recovery2.xml` (이것) |
|---|---|---|
| 파이프라인 | fusion2urdf → URDF → MJCF | fusion2xml (MJCF 직행) |
| 폐루프 | `connect crank_loop_close`<br>`body1="Crank_1_b"` (더미 바디) ↔ `Crank_1` | `connect connect_Crank_1_M_Top_1`<br>`body1="Crank_1"` ↔ `body2="M_Top_1"` (둘 다 실제 바디) |
| 메시 | 별도 재exported | **33개 전부 바이트 다름** |

메시 파일명이 서로 겹치지만 **내용이 다르다**. 두 `meshes/` 를 섞지 말 것.
**2026-08-19: 시뮬레이터 쪽 참조를 전부 이 빌드로 옮겼다** — `full_workflow.py`
(`RECOVERY2_MJCF`, 따라서 `full_workflow_rigid.py` 도), `Recovery2_only/` 3종,
`Fixture_only/` 스택 2종. 구 `회수장치2_description` 은 대조용으로만 남긴다.

경로를 ASCII 로 잡은 것은 의도적이다 — 한글 경로면
`paths.ascii_safe_mjcf` 미러를 타야 하고, 그 미러가 부분 복사 상태에서
영구히 막히는 버그가 있었다(커밋 320ffee).

## 시각 메시 전처리 `*_ss.obj` (2026-08-19 추가)

Genesis(pyrender) 의 smooth 셰이딩은 `trimesh.vertex_normals` 를 크리스 각도
구분 없이 그대로 써서, 볼트머리 같은 작은 디테일 부근에 **별모양 스파이크**를
만든다(원인·경위는 docs/DigitalTwin.md "고정장치/M0609 렌더링 스파이크
아티팩트 — 해결(2026-07-21)"). fusion2xml 빌드는 시각/충돌 geom 이 같은 STL 을
보고 있어서 이 아티팩트가 그대로 나온다.

그래서 구 `회수장치2_description` 과 같은 처방을 적용했다:

- `utills/smooth_shade_meshes.py` 로 33개 STL 을 `trimesh.smooth_shaded`
  (크리스 각도 기준 정점 분리 후 스무싱)로 재수출 → `meshes/<이름>_ss.obj`
- `recovery2.xml` 의 `<mesh>` 자산에 `<이름>_ss` 를 추가하고, **`*_vis` geom만**
  그것을 보게 했다. `*_col` geom 은 원본 STL 그대로다 — `_ss` 는 정점을 쪼갠
  결과라 non-watertight 이고 충돌/SDF 에 쓰면 깨진다.

재생성:

```
python utills/smooth_shade_meshes.py Crusher_Genesis/assets/robots/recovery2_mjcf/meshes --force
```

## 검증 (2026-08-18, MuJoCo)

`recovery2.xml` 단독 로드 → bodies=34, joints=3, eq=1, geoms=66, meshes=33
(`_ss.obj` 추가 후로는 meshes=66 — 시각 33 + 충돌 33).
크랭크 힌지에 0.5N·m 를 걸고 6초(3000스텝) 구동:

- 크랭크 +14.9rad(약 2.4회전) 연속 회전 — 사점에 걸리지 않는다
- 슬라이더 0 ~ +35.0mm 왕복 (스트로크 35.0mm) — 폐루프가 회전을 직선운동으로 전달
- 구속 잔차 최대 1.8mm 로 **유계**, 회전을 거듭해도 증가하지 않음
- 발산 없음

> 잔차를 볼 때 `qvel` 을 매 스텝 덮어써서 구동하면 구속 솔버의 보정을
> 무력화해 잔차가 단조 증가하는 것처럼 보인다. 토크로 구동해야 실제
> 거동이 나온다.

## 알려진 거친 부분

- 조인트 이름이 Fusion 자동생성 한글이다 — `슬라이더_35`, `회전_31`, `회전_29`.
- 원 빌드에 있던 렌더 확인용 변형(`recovery2_jaws.xml`, `recovery2_marked.xml`)과
  애니메이션 GIF(`views/`, 34MB)는 자산이 아니라 검증 기록이라 넣지 않았다.

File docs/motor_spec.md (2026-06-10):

# Motor & Actuator Specification

Crusher 시뮬레이션에 사용된 실제 모터 스펙과 MuJoCo 내 구현 방식을 정리합니다.

---

## 1. 실제 모터 — BL4281 (BLDC)

| 항목 | 값 | 단위 |
|---|-----|---|
| 모델 | **BL4281** | — |
| 종류 | BLDC (Brushless DC) | — |
| 정격(stall) 토크 | **0.185** | N·m |
| 무부하 속도 | **5,800** | RPM |
| 로터 관성 (J_motor) | **7.2 × 10⁻⁶** (`72e-7`) | kg·m² |

코드 상수 (`crusher_velocity_ctrl.py`):

```python
MOTOR_STALL_TORQ = 0.185      # [N·m]
MOTOR_NOLOAD_RPM = 5800.0     # [RPM]
MOTOR_INERTIA_KG = 72e-7      # [kg·m²]
```

---

## 2. 감속기

| 항목 | 값 |
|---|----|
| 감속비 (n) | **1 : 212** |
| 역구동 차단 | 있음 (self-locking) — 부하 시 크랭크 위치 유지 |

```python
GEAR_RATIO = 212.0
```

---

## 3. 크랭크 출력 (감속 후)

| 항목 | 계산식 | 값 | 단위 |
|---|---|----|---|
| Stall 토크 (τ_crank) | 실측 역산: F_slider × r | **12.5** | N·m |
| 무부하 속도 | 5800 ÷ 212 | **≈ 27.4** | RPM |
| 환산 관성 (J_refl) | J_motor × n² = 72×10⁻⁷ × 212² | **≈ 0.324** | kg·m² |
| 전달 효율 (η) | τ_crank / (τ_motor × n) = 12.5 / (0.185 × 212) | **≈ 32 %** | — |

```python
_J_REFL          = MOTOR_INERTIA_KG * GEAR_RATIO**2   # = 0.3236 kg·m²
_TAU_STALL_CRANK = 12.5                                # [N·m]  실측 역산
```

---

## 4. 크랭크-슬라이더 기구

| 항목 | 값 | 단위 |
|---|----|---|
| 크랭크 반경 (r) | **20** | mm |
| 커넥팅 로드 길이 (L) | **80** | mm |
| 운전 속도 | **8** | RPM |

```python
CRANK_R_M = 0.020   # [m]
ROD_L_M   = 0.080   # [m]
TARGET_RPM = 8.0
```

슬라이더 힘 공식 (크랭크 각도 θ 기준):

```
F_slider = τ_crank / (r × sin θ)
```

| θ | F_slider | 비고 |
|---|---|---|
| 90° | 12.5 / (0.020 × 1.000) = **625 N** | 실측 600–650 N ✓ |
| 60° | 12.5 / (0.020 × 0.866) = **722 N** | — |
| 30° | 12.5 / (0.020 × 0.500) = **1250 N** | TDP(사점) 근처 증폭 |

---

## 5. MuJoCo 액추에이터 구현

### 5-1. MJCF 원본 정의 (`Crusher_IsaacSim_colored.xml`)

```xml
<actuator>
  <motor name="Motor1_crank"
         joint="L3_Bevel_GearBox_1_L4_Shaft_1"
         gear="1"
         ctrlrange="-50 50" />
</actuator>
```

> 뷰어 단독 실행 시 사용하는 기본 토크 제어 액추에이터 (forcerange 미설정).

### 5-2. 시뮬레이션 런타임 오버라이드 (`crusher_velocity_ctrl.py`)

`_build_model()` 내에서 기존 `Motor1_crank` 요소를 제거하고 **velocity 액추에이터**로 교체합니다:

```xml
<velocity
  name="Motor1_crank"
  joint="L3_Bevel_GearBox_1_L4_Shaft_1"
  kv="14.9"
  gear="1"
  forcerange="-12.5 12.5"
  ctrlrange="-1.6755 1.6755" />
```

| 파라미터 | 값 | 의미 |
|---|----|---|
| `kv` | **14.9** N·m·s/rad | 속도 게인 = τ_stall / ω_target |
| `forcerange` | −12.5 ~ +12.5 N·m | 크랭크 stall 토크 상한 |
| `ctrlrange` | ±2 × ω_target | 목표 각속도 범위 |
| `gear` | 1 | 감속비는 환산 관성으로 별도 반영 |

kv 계산:

```
ω_target = 8 RPM × (2π / 60) = 0.8378 rad/s
kv = τ_stall / ω_target = 12.5 / 0.8378 ≈ 14.9  N·m·s/rad
```

```python
MOTOR_FORCELIM   = _TAU_STALL_CRANK                                     # 12.5 N·m
VEL_KV_DEFAULT   = _TAU_STALL_CRANK / (TARGET_RPM / 60.0 * 2 * math.pi)  # ≈ 14.9
```

### 5-3. 환산 관성 주입

고감속비 감속기의 반영 관성을 `L4_Shaft_1` body의 `diaginertia`에 더해 수치 안정성을 확보합니다:

```python
# _build_model() 내부
inertial.set("diaginertia",
    f"{orig_i0 + _J_REFL:.6f} {orig_i1:.6f} {orig_i2:.6f}")
```

`_J_REFL = 72×10⁻⁷ × 212² ≈ 0.3236 kg·m²`

---

## 6. 수치 안정성 검증

MuJoCo velocity 액추에이터의 안정 조건: `kv × dt / J_eff < 2`

| 조건 | kv | dt | J_eff | 안정 지수 | 결과 |
|---|----|----|---|---|---|
| 환산 관성 **미적용** | 14.9 | 0.002 s | ~4.2×10⁻⁵ kg·m² | ≈ 710 >> 2 | 발산 ✗ |
| 환산 관성 **적용** | 14.9 | 0.002 s | 0.324 kg·m² | ≈ 0.09 << 2 | 안정 ✓ |

> `timestep=0.001 s` (implicitfast) 사용 시 안정 지수 ≈ 0.046으로 더욱 안정적.

---

## 7. 시뮬레이션 파라미터 요약

| 상수 | 값 | 설명 |
|---|----|---|
| `GEAR_RATIO` | 212 | 감속비 |
| `MOTOR_STALL_TORQ` | 0.185 N·m | BL4281 정격 토크 |
| `MOTOR_NOLOAD_RPM` | 5800 RPM | 무부하 속도 |
| `MOTOR_INERTIA_KG` | 7.2×10⁻⁶ kg·m² | 로터 관성 |
| `_TAU_STALL_CRANK` | 12.5 N·m | 크랭크 stall 토크 |
| `_J_REFL` | 0.3236 kg·m² | 환산 관성 (J × n²) |
| `MOTOR_FORCELIM` | 12.5 N·m | velocity actuator forcerange 상한 |
| `VEL_KV_DEFAULT` | ≈ 14.9 N·m·s/rad | velocity actuator 게인 |
| `TARGET_RPM` | 8 RPM | 운전 속도 |
| `CRANK_R_M` | 0.020 m | 크랭크 반경 |
| `ROD_L_M` | 0.080 m | 커넥팅 로드 길이 |

---

## 8. 관련 파일

| 파일 | 역할 |
|---|---|
| [`MJCF/Crusher_IsaacSim_colored.xml`](../MJCF/Crusher_IsaacSim_colored.xml) | MJCF 원본 (motor 토크 액추에이터) |
| [`20260603/crusher_velocity_ctrl.py`](../20260603/crusher_velocity_ctrl.py) | 실제 모터 스펙 상수 정의 + velocity 액추에이터 오버라이드 + 환산 관성 주입 |
| [`20260527/crusher_tablet_sim.py`](../20260527/crusher_tablet_sim.py) | 인터랙티브 시뮬레이션 (MOTOR_CTRL = −0.5 N·m, stall 역전 포함) |
| [`20260526/crank_acceleration.py`](../20260526/crank_acceleration.py) | 크랭크·슬라이더 가속도 측정 (MOTOR_CTRL = 10 N·m 개루프 테스트) |

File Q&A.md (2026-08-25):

# Q&A — 2026-08-25 ~ 08-26 세션

이 세션에서 오간 질문과 답을 시간순으로 정리한다. 근거 수치를 같이 남긴다 —
결론만 남기면 나중에 다시 재봐야 하기 때문이다.

작업 브랜치: `cost-remeasure-genesis133` (HEAD `e192402`)

---

## 1. GitHub에서 변경사항 가져오기

> **Q.** github 에서 변경사항 가져와줘

`fetch` 결과 두 가지가 나왔다.

- `origin/cost-remeasure-genesis133` 이 **GitHub에서 삭제**돼 있었다. 그 커밋들은
  전부 `origin/rigid-process-validation` 에 흡수돼 있어서 거기서 fast-forward 했다.
- 새 커밋 1건: `e192402` "압착 공정 3건 규명 — 힘 상한 부재, 벽 형상 오독, 실링 두께 제약"

merge 를 막은 건 `_bag_seal_uv.obj` 였는데, 워크트리 해시가 HEAD와 동일해
(`f19b39f8`) 실제 수정이 아니라 LF/CRLF 개행 설정 때문이었다. 인덱스만 정리하고 진행.

---

## 2. "로컬 main이 7커밋 앞서 있다"는 게 무슨 뜻인가

> **Q.** 이게 무슨말이야? 로컬 변경사항이 더 앞서있다고? 지금 깃허브 상태랑 뭐가 다른지 알려줘

**로컬 전용 커밋은 하나도 없었다.** 앞선 답변에서 "푸시 안 됐다"고 쓴 건 부정확했다.
커밋은 전부 GitHub에 있었고, 뒤처진 건 GitHub의 `main` **브랜치 포인터**뿐이었다.

| | 커밋 | 날짜 | 최신 대비 |
|---|---|---|---|
| GitHub `main` | `3d96b23` | 8/11 | 19 커밋 뒤 |
| 로컬 `main` | `4b003ea` | 8/14 | 12 커밋 뒤 |
| 현재 브랜치 = `origin/rigid-process-validation` | `e192402` | 8/25 | 최신 |

세 포인터가 같은 일직선 위에 있었다. `git log --all --not --remotes` 가 빈 출력이라
로컬에만 있는 커밋이 0건임을 확인했다.

---

## 3. main 포인터 전진 + fusion2xml 위치

> **Q.** 메인브런치의 포인터도 앞당겨줘. 그리고 utils 에 내가 만든 fusion2xml이
> 없더라고 이거 주석 달아서 내 레포에 추가해줘

**main 전진**: `3d96b23` → `e192402`, 19커밋. 순수 fast-forward라 force 없이 push.

**fusion2xml**: 착오였다. `utils/fusion2xml/` 에 8개 파일 전부 있었고, push 하기
*전*의 GitHub `main`(`3d96b23`)에도 이미 있었다.

- 리포 루트에 **`utils/` 와 `utills/` 가 둘 다 존재**한다. 나머지 스크립트는 전부
  `utills/` 에 있고 `utils/` 안에는 fusion2xml 하나뿐이라 헷갈리기 쉽다.
- Fusion 360 애드인 폴더는 **junction** 이라 별도 사본이 아니다:
  `%APPDATA%\Autodesk\...\AddIns\fusion2xml` → `<repo>\utils\fusion2xml`
- 주석도 이미 충실했다(모듈·함수 docstring + 171줄 README).

---

## 4. Left_Wall 을 두 body 로 분리해 볼록분해를 피할 수 있는가

> **Q.** 2_Left_Wall의 플런지 형태를 `2_Left_wall_1` + `3_Left_wall_1` 두 body 로
> 분리해서, 하나로 묘사했을 때 collision mesh가 이상하게 볼록분해 되는 걸 방지해봤다.
> 분리하여 돌출된 플랜지 형태를 묘사하고자 하는데 가능한가?

**가능하다.** 신규 export 는 구조적으로 맞게 나왔다 — 조인트 없는 자식 body 는
MuJoCo에서 부모에 용접되므로 동역학은 한 덩어리, 충돌은 두 개의 독립 shape 다.

| | 실부피 | convex hull | hull 대비 |
|---|---|---|---|
| `2_Left_Wall1_1` (플랜지) | 5,850 mm³ | 5,850 mm³ | **100.0%** |
| `3_Left_Wall_1` (본체) | 32,273 | 116,090 | 27.8% |
| 합계 | **38,123** | — | — |
| 예전 통짜 `L2_Left_Wall1_1` | **38,123** | 136,890 | 27.8% |

부피가 소수점까지 같다. 플랜지는 verts 8개 = 정확한 18×5×65mm 직육면체.

**다만 분리만으로는 볼록분해 문제가 안 풀린다.** 본체는 여전히 ㅁ 프레임(27.8%)이라
단일 geom 으로 두면 hull 이 실부피의 3.6배가 되어 세로부재 사이 55mm 개구부
(impact plate 통로)를 메운다. 본체는 CoACD 를 계속 돌려야 한다.

**신규 export 를 그대로 쓰면 막히는 것 3건**

1. **벽 슬라이드 축이 틀렸다** — `48_0276 axis="0 0 1"` = 65mm 폭 방향.
   실제 구동축은 root x (가이드레일 60mm, 랙기어 120.18mm 가 x 방향).
2. **간격이 0.5mm 늘었다** — 새 CAD 의 Left_Wall 이 그만큼 물러나 있다.
   플랜지 12.00 → **12.50mm**, 본체 17.00 → **17.50mm**.
3. **§18-5 는 미구현** — 플랜지가 여전히 움직이는 벽의 자식이고, Wall3 상단보다
   1.00mm 위라 두 벽이 높이에서 안 겹치는 문제도 그대로.

---

## 5. Left_Wall 만 가져와서 적용

> **Q.** 그냥 다른건 참고하지 말고, Left_wall 쪽만 참고해서 사용해줘

조인트는 현재 모델 것을 유지하고 형상만 이식했다.

- 새 파일: `assets/MJCF/build_leftwall_split.py` + STL 7개
- 좌표 오프셋은 하드코딩하지 않고 공통 부품 4개(Wall1/Wall2/Wall3/PLATE)로
  유도 후 교차검증 — 네 부품이 `+27.124 / −159.074 / −1.423 mm` 로 완전 일치.
- `full_workflow.py` 에 `LEFTWALL_SPLIT`(기본 켜짐) + `_split_leftwall_collision()`

**중간에 낸 오답 정정**: "hull 11개가 XML에 연결돼 있지 않다"고 했는데 틀렸다.
실제 소스는 `paths.MJCF_MAIN` = **`Crusher_IsaacSim_colored.xml`** 인데
`Crusher_IsaacSim.xml` 을 읽고 있었다. colored 쪽에는 CoACD hull 11개가 이미
`group="3"` 충돌 geom 으로 배선돼 있었다. **즉 이 작업은 버그 수정이 아니라 개선이다.**

| | 기존 (hull 11) | 신규 (hull 5 + box 1) |
|---|---|---|
| 충돌 geom | 11 | **6** |
| 부피 충실도 | 38,847 mm³ (101.9%) | **38,694 mm³ (101.5%)** |
| 플랜지 | `hull_000` 5,895 (100.8%) | **정확한 box 5,850 (100.0%)** |
| AABB 겹치는 쌍 | 11 | **0** |

---

## 6. 두 body 로 나눈 걸 쓰고 있나? 강체 접합인가?

> **Q.** 현재 left_wall 이부분을 두개의 바디로 분할한거를 사용하고 있는거지?
> 연결은 강체 접합 시키고?

**아니다 — 바디가 아니라 geom 을 나눴다.** 기존 `L2_Left_Wall1_1` 한 바디 안의
geom 두 종류이고, 자식 바디도 조인트도 weld 제약도 없다. 같은 링크에 들어 있으니
강체 접합은 구조적으로 자동이다.

이렇게 한 이유: 볼록화는 **geom 단위**라 충돌 결과가 동일하고, 링크가 늘지 않아
구조 위험이 없다. §18-5 처럼 플랜지를 고정 프레임에 매달 때 진짜 body 로 올리면 된다.

---

## 7. 그린 게 STL 아니냐, Genesis 충돌메시는 다를 텐데

> **Q.** 너가 그린건 그냥 메쉬 파일이고 Genesis 상에서 비춰지는 충돌메쉬는
> 다를거같은데

**타당한 지적이었다.** 확인해보니 이번엔 같았지만, 확인 전엔 알 수 없는 게 맞다.
`scene.build()` 후 `geom.get_verts()` 로 솔버가 실제로 들고 있는 world 좌표를 뽑아
다시 그렸다.

| | 조각 수 | STL 합계 | Genesis 합계 | 차이 |
|---|---|---|---|---|
| 기존 | 11 | 38,847 mm³ | 38,847 mm³ | **0.0** |
| 신규 | 6 | 38,694 mm³ | 38,694 mm³ | **0.0** |

정점 수까지 1:1로 같았다. 이유는 둘 — **이미 볼록한 메시의 convex hull 은 자기
자신**이고, `decimate_face_num=500` 인데 조각들은 face 가 12~26개뿐이라 감축 대상이
아니다. 통짜 concave 메시였다면 여기서 hull 하나로 뭉개졌을 것이다.

---

## 8. Wall_1 과 Left_wall_1 이 맞물리는지 테스트

> **Q.** Wall_1 이랑 Left_wall_1 이 서로 맞물리는지 테스트를 해보자.
> Left_wall_1이 정확하게 Wall_1 맞물려야한다

정적 진단만으로 결론이 났다(폭·높이가 안 겹치면 q 를 아무리 줘도 못 만난다).

- **플랜지는 세 고정벽 전부와 높이가 안 겹친다.** `L2_Wall3_1` 과 −1.00mm,
  `L1_Wall1_1`/`L1_Wall2_1` 과 −67.00mm → **영영 못 만난다.**
- **본체 조각들은 `L2_Wall3_1` 과 겹친다** — x 간격 17.50mm 라 **q ≤ −17.50mm**
  에서 접촉.
- `L1_Wall1_1` 과 겹치는 건 본체 조각 하나뿐(폭 28.99, 높이 5.00mm).

즉 `CLAMP_TARGET=−12mm` 로는 본체가 Wall3 에 닿지 않고, 플랜지는 애초에 맞물릴 수
없다. §18-5 가 지적한 상태 그대로다.

---

## 9. Wall_1 의 충돌메시는 어떻게 되어 있나

> **Q.** 일단 Wall_1 쪽은 충돌메쉬가 어떻게 되어있는지 알려줘

| | 원본 STL | Genesis 충돌 |
|---|---|---|
| verts / faces | 480 / — | **27 / 50** |
| 부피 | 20,425 mm³ | **22,080 mm³** (1.08배) |
| 형상 | 볼트 구멍 6개 뚫린 평판 | **구멍이 메워진 통짜 슬래브** |

22,080 = 64 × 5 × 69 이므로 AABB 를 꽉 채운 직육면체와 같다. 다만 구멍은 내부
특징이고 Left_Wall 을 마주보는 면(world x = −336.28)은 원본과 정확히 같아
**맞물림 판정에는 영향이 없다.**

고정 구조물은 전부 볼록 hull 1개씩이고 손실이 1~12%뿐이다 — 원래 볼록에 가까운
판재라 Left_Wall(ㅁ 프레임, 3.6배)과 상황이 다르다.

| # | 부품 | verts | GS 부피 | 원본 | 부풀림 |
|---|---|---|---|---|---|
| 0 | `base_link` | 29 | 480,000 | 476,732 | 1.01배 |
| 2 | `L1_Wall1_1` | 27 | 22,080 | 20,425 | 1.08배 |
| 3 | `L1_Wall2_1` | 19 | 13,440 | 11,957 | 1.12배 |
| 4 | `L2_Wall3_1` | 25 | 79,200 | 77,599 | 1.02배 |

---

## 10. full_workflow 테스트

> **Q.** 일단 Full_sequence.py 한번 테스트 가자

```
[mjcf] 옛 geom 12개 -> 본체 hull 5 + 플랜지 1 + 시각 1   간격 12.50 / 17.50mm
[slot] gap_width=12.5mm            <- 슬롯 계산이 새 형상을 따라감 (12.0 -> 12.5)
[phase] clamp @done  wall=-8.25mm  (잔여: 플랜지면 4.25mm / 본체면 9.25mm)
[RESULT] verdict=PASS  오차=-1.0mm
[timing] build=16.4s  steps=250.4s (2430 steps, 103.1ms/step)
```

**IPC build 통과** — 유일하게 걸었던 리스크(`Intersection detected`)가 해소됐다.
스텝 시간 103.1ms 로 정상(발산 런은 4.7s/step).

단, `GRIP_OFFSET_MM` 기본값이 −28 이라 참조 런(+0mm)과 변인이 둘이고, 이 판정은
비결정적이라 한 번 PASS 로 개선을 주장할 수 없다.

---

## 11. Crusher 1분 운전

> **Q.** 이 상태에서 Crusher를 1분간 작동시키는 시퀀스를 수행시켜보자

`full_workflow.py` 에 **Phase 11 `crush`** 를 추가했다. 사양·패턴은 새로 정하지 않고
`Crusher_only.py` 에 확립된 것을 따랐다.

| 항목 | 값 | 근거 |
|---|---|---|
| 회전수 | 8 RPM (0.8378 rad/s) | `docs/Crusher.md` §1 |
| 제어 | velocity + 토크 클램프 | position 램프는 접촉 시 PD 가 무한 토크 |
| 토크 상한 | ±12.5 N·m | `Crusher.md` §2-2 |

기본 꺼짐(`CRUSH_SECONDS=0`). 60s = DT 5e-3 에서 12,000 스텝이라 기존 런에 16분을
더한다.

```
[phase] crush @done  크랭크 +2832.8deg (7.87 바퀴)
[crush] 정제 3.97x5.00x3.96 -> 3.98x5.00x3.95 mm
[timing] steps=964.8s (14430 steps, 66.9ms/step)  합계=975.8s
```

---

## 12. 회수장치 클램프를 현재 샘플백 규격으로

> **Q.** 회수 장치에서 클램프하는 코드가 있을텐데, 그거 지금 사용하고 있는
> 샘플백 규격으로 다시 테스트해보자

`recovery2_bag_clamp.py` 를 3건 수정했다.

1. **봉투** `_seal1mm` → `_sealslab3mm`. 평탄 실링부 폭은 둘 다 가장자리 8mm 로
   같아 `SEAL_BAND_WIDTH` 는 그대로. 바뀌는 건 두께 1.0 → **3.0mm**.
2. **천 물성**을 full_workflow 와 일치: `t=0.1mm, E=4.0e6` → `t=1.0mm, E=4.0e5`
   (`E×t = 400 N/m` 보존).
3. **압착 틈새를 고정 상수 → 관계식으로.** `CLAMP_SLIDER_MM=0.8` 은 옛 조합에 손으로
   맞춘 값이라, 봉투만 바꾸면 실효 두께가 1.2 → 5.0mm 가 되는데 틈새는 0.8 로 남아
   4.2mm 를 억지로 밀어넣게 된다.

```
실효 두께 = 실링부 자유 두께 + 2 × CLOTH_THICK
목표 틈새 = 실효 두께 − CLAMP_PRESS_MM(0.4)
```

회귀 확인: 예전 입력을 넣으면 실효 1.20 / 틈새 **0.80mm** 로 하드코딩 값과 정확히
일치 → 재튜닝이 아니라 리팩터.

**결과 — 시퀀스는 돌았고 파지는 실패**

```
[cfg] 실링 3.00mm + 2 x 1.00mm = 실효 5.00mm  ->  틈새 4.60mm (auto)
A. 턱 열림 +35.05mm   B. 실링부 하단 z 58.00mm ✓   C. 압착 311.1deg / +4.60mm ✓
D. 해제 후 낙하량 +36.47mm  (탄성 스냅 +3.33 / **미끄러짐 +33.14**)
```

새로 넣은 정합성 경고가 원인을 잡아냈다:

```
[경고] 씬 실측 실링두께 31.038mm 가 STL 값 3.000mm 와 다르다
```

상단 중앙만 잡고 매달린 봉투가 파우치처럼 벌어져 실링부 정점이 x 로 31mm
(해제 시점 52mm, 낙하 중 73mm)에 퍼져 있다. 턱은 4.60mm 로 닫는데 물어야 할 천이
그 앞 30~50mm 에 흩어져 있다. **틈새 값 문제가 아니라 투입 시점의 봉투 형상 문제다.**

---

## 13. 정제가 왜 안 맞는지 확인

> **Q.** 정제가 왜 안 맞는지 sideview로 확인해줘

**전제가 틀렸다 — 정제는 매 회전 맞고 있었다.** 로그 샘플 간격(2.0s)이 회전
주기(7.5s)보다 짧아 접촉 구간에 샘플이 걸릴 때만 잡혔던 것이다.

| 샘플 | 크랭크 360° 나머지 | 회전 | 정제 x |
|---|---|---|---|
| t=4.0s | 151.5° | 1번째 | 3.97 → **0.06mm** |
| t=12.0s | 169.3° | 2번째 | → **0.05mm** |
| t=20.0s | 193.3° | 3번째 | → **0.33mm** |
| t=28.0s | 217.2° | 4번째 | → 3.91mm (끝자락) |
| t=34.0s | 145.2° | 5번째 | → 3.35mm (진입) |
| t=42.0s | 169.1° | 6번째 | → **0.23mm** |
| t=50.0s | 193.1° | 7번째 | → **0.39mm** |

7회전 전부 크랭크 145~217° 구간에서 잡힌다 — 슬라이더 최대 전진(θ=180°) 부근으로
크랭크-슬라이더 기구상 맞는 위치다. `wall` 도 그때마다 −8.00 → −7.89mm 로 밀린다.

**진짜 문제는 정제가 완전 탄성체라는 것이다.**

```python
gs.materials.FEM.Elastic(E=5.0e4, nu=0.45, model="stable_neohookean")
```

소성도 파괴도 없어 매 타격 99% 압축(3.97 → 0.05mm)돼도 100% 원상복구된다.
8바퀴를 돌려도 최종 크기가 시작과 같을 수밖에 없다. E=50kPa 는 고무보다 무르다
(실제 정제는 GPa 급 취성). 이 시퀀스로 검증되는 건 "분쇄가 되는가"가 아니라
**"타격이 정확히 전달되는가"** 이고, 후자는 명확히 성립한다.

---

## 14. Crushing 영상이 어디까지 뽑혔나

> **Q.** 지금 Crushing 이 추가된 영상은 어디까지 뽑아졌지?

**60초 전부.** 영상 3종 모두 `01:12.14`.

```
RESULT/grip-28mm/full_workflow_grip-28mm_yoff+0.0mm_20260826_043355_{overview,bagcam,sideview}.mp4
```

크러시 전 12.15s + 크러싱 60.00s = **72.15s**, 영상 72.14s 로 시뮬 시간과 1:1.
크러싱 구간은 영상 **12.15s ~ 72.15s** 의 마지막 60초이고 크랭크 7.87바퀴가 다 담겼다.

프레임 매핑을 처음에 잘못 계산했는데, Genesis 가 `render()` 호출 수가 아니라
**시뮬 시간 페이스로 녹화**하기 때문이었다(크러시 없는 런: 12.15s × 30fps ≈ 347프레임).
`CRUSH_RENDER_EVERY=10` 은 렌더 호출을 줄여 속도만 벌었고 영상 길이에는 영향이 없다.

---

## 15. 공압그리퍼 위치 조정 (진행 중)

> **Q.** 공압그리퍼의 위치도 Full_sequence 내에서 조정해야한다. 위치는 샘플백의
> 중앙에 정확하게 공압 그리퍼의 양측면이 닿을 수 있도록 위치 조정

확인 결과 **석션V1 쪽 기구**였다. `석션V1.xml` 의 L/R 한 쌍이 공압 그리퍼다:

```
Dummy_1                              slide x  (리니어 스테이지)
├ L_E-SMLG9H-100-ES10_2_1            slide +y, range [-0.05, 0]
└ R_E-SMLG9H-100-ES10_2_1            slide -y, range [-0.05, 0]
   (equality 로 두 조가 동기 구동)
```

`E-SMLG9H-100-ES10` 은 SMC 공압 그리퍼 모델명이고, 두 조가 ±y 로 마주 보며 닫힌다 —
스케치와 일치한다.

**현재 배치의 문제**: `SUCTIONV1_POS` 는 **흡착컵** 중점을 회수장치2 F링크 중점에
맞춘 값이다(2026-07-29). 공압 그리퍼 턱을 봉투 중앙에 맞추려면 정렬 기준이 바뀌므로
흡착컵 정렬과 양립하지 않을 수 있다.

*여기서 세션이 중단됐다 — 정렬 기준을 어느 쪽으로 할지 결정이 필요하다.*

---

## 부록 — 이 세션에서 추가된 환경변수

| 변수 | 기본 | 뜻 |
|---|---|---|
| `LEFTWALL_SPLIT` | `1` | Left_Wall 충돌 분리 on/off |
| `CRUSH_SECONDS` | `0` | 크러셔 운전 시간(초). 0 이면 생략 |
| `CRUSH_RENDER_EVERY` | `10` | 크러시 구간 렌더 솎기 |
| `CRANK_TORQUE_LIM_NM` | `12.5` | 크랭크 토크 상한 |
| `CLAMP_MM` (recovery2) | `auto` | 압착 틈새. `auto` 면 실링 두께에서 산출 |
| `CLAMP_PRESS_MM` (recovery2) | `0.4` | 눌러 물 양 |
| `BAG_STL_NAME` (recovery2) | `_sealslab3mm` | 봉투 메시 |
| `CLOTH_THICK_MM` / `CLOTH_E` (recovery2) | `1.0` / `4.0e5` | 천 물성 |

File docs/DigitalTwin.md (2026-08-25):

# Digital Twin — 시뮬레이션 전략 노트

시뮬레이션에 대한 디테일한 전략들을 적는 공간.

> 관련: 실험·트윈·한계 데이터 구분과 S-N 재검토는 [`DataInventory.md`](DataInventory.md) 참고.

---

## 목차

1. [개요](#1-개요)
2. [시뮬레이터 선정 전략](#2-시뮬레이터-선정-전략)
3. [Crusher](#3-crusher)
4. [Gripper](#4-gripper)
5. [Sample Bag](#5-sample-bag)
6. [Tablet](#6-tablet)
7. [FEM 방식으로 모델링](#7-fem-방식으로-모델링)
8. [발생할 수 있는 문제 사항](#8-발생할-수-있는-문제-사항)
9. [Solver / Coupler 조합 실험 기록](#9-solver--coupler-조합-실험-기록)
10. [피드백](#10-피드백)
11. [Visualization options](#11-visualization-options)
12. [현 시점 우선순위 및 미해결 문제 (2026-08-08)](#12-현-시점-우선순위-및-미해결-문제-2026-08-08)
13. [공정 검증 전략 — 전(全) Rigid 선행 모드](#13-공정-검증-전략--전全-rigid-선행-모드)

---

## 1. 개요

**Crusher 압착력 → 봉투 → 알약**: 3-way coupling.

- Crusher는 강체 모터 구동
- 봉투는 PBD
- 알약은 rigid

> **CPU 백엔드에서 안정성 모니터링 필수** (이전 보수적 권고대로).

---

## 2. 시뮬레이터 선정 전략

- 나의 기구는 현재 **Closed Kinematic loop**를 형성하고 있음. 따라서 Tree 구조로 풀거나, Equality constraint 같은 동등성 제약을 지원하지 않는 시뮬레이터는 어려울 수 있다. 비록 mimic joint 등으로 Crank-slider mechanism을 개선하는 방법을 고려해볼 수는 있으나, 이는 다항식(polynomial) 한 조건에서 푸는 것이 아닌 이상 정상적이지 않은 Output이 생성된다.
  - → **이러한 이유로 폐루프 시스템을 구현할 수 있는 시뮬레이터 선정이 필요하다. MJCF를 지원해야 한다.**
- 나의 기구는 현재 슬라이더 끝에 발생하는 **반력 프로파일**이 중요하다. 따라서 물리적 충실도가 높은 시뮬레이터를 선정하는 것이 중요했다. 최근 Nvidia의 동향을 보았을 때, Isaac Sim의 PhysX는 여러 가지 물리적 충실도에 있어 한계가 보인다.
- 개발 환경의 자유도가 높은 시뮬레이터가 좋다. 이를테면 오픈소스이거나, 개발진들과의 소통이 자유로운 시뮬레이터.
- 또한 위의 맥락에서 최근 계속해서 **업데이트를 활발히 진행**하고 있는 시뮬레이터가 좋다.
- Twin인 만큼 **공정 시뮬레이션**에 집중해야 할 것 같다. 사실 물리적 충실도가 높으면 매우 좋다고 생각하지만, 현실과는 괴리가 존재하기 때문에 이를 calibration 하는 과정이 매우 어렵다. 또한 현실에서의 고상 시료를 다루는 문제를 센싱하기가 어렵기 때문에, **공정 절차를 중심으로 시퀀스를 구성하는 것이 좋아 보인다.**
- 물리적 거동을 묘사하는 솔버에 대한 **수학적 모델이 명확**해야 한다. 수학적 모델이 명확하지 않다면, 논문을 작성할 때 문제가 발생할 수 있다.
- 파우더나, 알약이나, 강체나 다양한 재료들에 대한 계산이 이루어져야 한다. 따라서 Digital Twin 논문에서 늘 나오는 **Multi-Scale 문제**라고 볼 수 있고, 이를 해결하기 위해서 다양한 솔버가 지원되어야 한다. 우선 Rigid collision dynamics 계산은 무조건 해야 하고, 그 밖에 **PBD, MPM** 솔버 등이 지원되어야 한다.

> 이와 같은 이유로 **MuJoCo, Isaac Sim, Genesis** 중 **Genesis**를 선택하게 되었다.

---

## 3. Crusher

이 기구는 처음부터 끝까지 직접 설계한 기구이다. Geometry, motor, joint, link 등의 자세한 정보는 [`motor_spec.md`](motor_spec.md)나 [`Crusher.md`](Crusher.md) 파일을 참고하면 될 것이다.

### 3-1. Digital Twin을 위한 Step

1. **Fusion 360**을 통해서 설계를 한다.
2. 설계된 기구에 각 링크를 fixed joint, slide joint, revolute joint 등으로 접합 연결을 한다.
3. **Fusion2URDF** GitHub extension을 통해서 robot description file인 **URDF** 파일로 export 한다.
4. URDF 파일을 **MJCF** 파일로 변환하는 과정이 필요하다.
   1. URDF에서는 내가 사용한 crank-slider(4절 링크 기구)를 묘사하기 어렵다. 더군다나 active joint를 통해 passive joint의 각도를 모방하는 mimic joint는 polynomial한 함수로만 묘사할 수 있기 때문에, 회전운동을 선형운동으로 변환하는 방식의 Crank-slider 메커니즘에는 사용이 어렵다.
   2. 따라서 MJCF를 통해서 이를 묘사할 수 있는데, **동등성 제약 조건(Equality Constraint)**을 토대로 이를 묘사할 수 있다. 이는 제약을 통해서 두 링크를 강제로 붙어있게 만드는 방식이며, 실제로 MuJoCo 논문(**Convex and analytically-invertible dynamics with contacts and constraints: Theory and implementation in MuJoCo**)에서는 이 폐루프에 대해서 설명하고 있다.
   3. 크랭크 슬라이더 구조 상, **Ground–Crank–Connecting rod–Slider–Ground** 이런 식으로 이어져 있다. 나는 Slider를 두 부분으로 나눠, `link3`–`shaft` 식으로 rigid joint로 구성해 놓았다. 그 후 폐루프 구조를 끊어내기 위해 `link3`–`shaft` 부분의 Rigid Joint를 끊어낸 후, **Equality Constraint**를 통해서 묶어 놓았다.
5. MJCF로 변환한 파일을 **Genesis** 시뮬레이터에 업로드한다.
6. **Velocity control**로 제어해야 한다.
   1. Position control로 제어하게 되면 제약을 빠르게 따라가기 위해서 모든 링크가 분해되는 현상이 발생한다.

### 3-2. 디테일한 설명

- 후면에 있는 샘플백을 고정하기 위한 홀더나, Impact plate, Wall_1의 경우에는 충돌 판정이 원활히 되어야 한다. 따라서 이 둘을 제외한 mesh들은 실제로 **self collision이 발생하지 않아야 할 지역**이다. 물론 볼록분해로 분해할 수는 있겠으나, 필요가 없기 때문에 모두 **collision-free한 객체**로 둔다.
- 다만, 샘플백을 고정하기 위한 홀더(**Left_Wall**)의 경우에는, 충돌이 켜져 있어야 하며, impact plate를 통과해야 하기 때문에 **볼록분해를 수행**한 상태이다.
- **사용한 테크닉:** 볼록분해 / self collision을 피하기 위해 엔티티 대부분을 collision-free한 엔티티로 만들기.

---

## 4. Gripper

- 사용하고 있는 제품은 **Onrobot 사의 RG2-v2**로, 현재 description 파일을 찾아보고 있는데, 기본적으로 Gripper는 모두 폐루프 시스템이기 때문에, description file을 작성할 때 여러 테크닉이 필요하다.
  - **폐루프를 사용하면 안 되는 이유:** RNE(Recursive Newton-Euler) 계산 과정에서 각 조인트에서 발생한 운동학 트리가 아니라면 상위 노드로 올라가는 움직임이 무한히 반복되기 때문에, 일종의 모든 노드가 연결되어 있는 그래프를 사용하면 안 되고 **운동학 트리(kinematic tree)**를 사용해야 한다.
- 따라서 이런 시스템에서 다음 두 개의 가이드라인이 권고된다.
  1. Revolute Joint를 통해서 하나의 **Active Joint**를 만들고 다른 조인트들을 **mimic**하는 구조의 description.
  2. Mimic Joint를 사용하지 않고, 어차피 회전운동을 선형운동으로 평행시키는 조인트이기 때문에 **Prismatic Joint**로 description하는 방식.

  → 기존 description 파일(franka emika panda 등)에서는 **2번 방식**을 선택하는 것으로 보인다. 따라서 2번 방식으로 간다.

### 4-1. 상대적으로 차순위 문제 (완벽하게 하려고 하지 말자)

- 그리퍼가 현재는 Revolute Joint–mimic joint가 아니라 **Slide joint**를 사용하여 묘사하고 있기 때문에, 이를 해결해야 실제 환경과 비슷하게 동작시키는 것이 가능해진다. 그렇게 설계할 수 있도록 해야 한다. → 위에서 설명한 **1번 방식의 구현**.
- 이 방식으로 가야 하는 이유는 파지하는 위치도 Rev joint냐 slide joint냐에 따라서 달라진다. 또한 slide joint로 작동시킬 때 **시각적으로 기구가 분리되는 듯한 현상**이 포착된다.

---

## 5. Sample Bag

- **PBD 솔버**로 풀어내려고 한다.
  - PBD 솔버가 가지고 있는 제약 함수를 통해서 비닐봉투 느낌, 혹은 약포지 느낌을 묘사하려고 한다.
  - FEM 솔버로 푸는 것이 정확하긴 하나, 어느 정도 물리적 충실도는 양보하고 **빠른 속도**를 선택.
  - 변형체지만 강성이 강하고 어느 정도 바스락바스락거리는 종이 느낌이 존재하기 때문에, 이를 구현하기 위해서는 **bending에 대한 값**들을 좀 조절하는 것이 좋아 보인다.
- 추가로 파지할 때 디테일이 필요하다고 생각하는데, 파지할 때 PBD 솔버 특성상 **두 particle의 간격이 일정 이상으로 가까워지지 못하게끔 하는 제약 조건**이 따로 명시되어 있다. 따라서 일종의 닫으면서 잡아 올리는 행동을 할 때 이런 제약 조건이 깨질 수 있기 때문에 이에 대한 고려가 필요하다.
  - particle의 거리 최솟값에 대한 조정을 수행(불안정해질 수는 있음. 이는 제약식과 관련)하고, 파지력과 마찰을 통해 잡는 물리적인 행위를 묘사할 수 있는지 고려.
- 생각보다 **stiffness를 작게** 만들어야, Crusher 단계에서 샘플백을 고정하는 홀더가 역할을 잘 수행할 수 있음.
- 마지막으로 위와 연결되는 핵심이라고 생각하는데, 공정 절차가 비닐백에 강체를 담고 이에 충격을 가하게 되면 가루 형태가 만들어진다. 이는 **MPM 솔버, PBD 솔버** 등의 파우더를 표현할 수 있는 솔버를 사용해야 할 듯하다. crushing 공정이 끝난 샘플백을 매니퓰레이터를 통해 이송하고, 회수 장치에 들어간 후 MPM 혹은 PBD 재료의 파우더를 접시에 담는 것까지가 목표이다.
  - 문제는 **MPM → Rigid → PBD** 이 3단 커플링이 잘 될지가 의문이다.
- 샘플백 이송도 문제이다. 현재 파지를 해보고 있는데, 생각보다는 파지가 잘 되질 않는다.

### 5-1. 백엔드 이슈 — *해결됨* (2026-06-30)

이전: Genesis 1.0.0부터 Taichi → **Warp** 전환 시 5080/5090 호환 안 됨.
→ 관련 이슈: https://github.com/Genesis-Embodied-AI/genesis-world/issues/2942

**원인 판명**: GPU 호환 문제가 아니라 **그래픽 드라이버 버그**. 드라이버 업데이트 후
정상 작동 확인.

**현재 표준 (2026-06-30 결정)**:
- Genesis **v1.2.0** 으로 통일 (`C:\genesis-world\` source 기준)
- env: **`isaacsim`** (Python 3.11, Warp backend, uipc 포함)
- Genesis_env (Python 3.10, 0.2.1, Taichi) 는 deprecated — 신규 작업 안 함

> 과거 SAP 결과(`fem_uniaxial_20260629_*` 등)는 Genesis 0.2.1 + Taichi 산물이라
> 새 환경 결과와 직접 비교 시 백엔드 차이 고려 필요.

**[정정] env는 conda `isaacsim`이 아니라 standalone Python (2026-07-15 확인)**:
위 "env: `isaacsim`" 표기는 부정확했다. 실제로 Genesis(v1.2.1, editable,
`C:\Users\user\Desktop\Genesis`)+pyuipc+torch+warp-lang 스택이 설치된
인터프리터는 `C:\Users\user\AppData\Local\Programs\Python\Python311\python.exe`
(standalone Python 3.11.9, conda 아님)이다. conda env 3개(`TabletCrusher`,
`isaac_sim`, `mujoco_env`)에는 genesis-world가 전혀 없다 — `isaac_sim`
conda env는 이름이 비슷해 헷갈리지만 실제로는 NVIDIA Isaac Sim 5.0.0
(별개 제품) 전용이다. Genesis/IPC 스크립트 실행 시
`C:\Users\user\AppData\Local\Programs\Python\Python311\python.exe <script>`
를 직접 호출할 것(conda activate 불필요/무의미).

**[재정정] 현재 인터프리터는 conda env `crusher_genesis` (2026-08-03 확인)**:
위 두 경로(`C:\Users\user\...`, `C:\Users\simuser\...`) 모두 지금은 존재하지
않는다. Genesis 1.3.1 + quadrants 1.2.0 스택이 실제로 설치된 인터프리터는

```
C:\Users\simuser\miniconda3\envs\crusher_genesis\python.exe
```

이다. 실행 로그(`_run_reposition_check.log` 등)의 site-packages 경로로 확인.

### 5-2. 실링부 마찰 파지 — *해결됨* (2026-07-13)

M0609+RG2 로 봉투 옆면 실링부(~1cm)를 순수 접촉+마찰로 파지(weld 없이).

- **PBD.Cloth + 핑거 mesh 접촉 → 즉시 폭발.** 5-1의 우려가 실제로 발생(자기충돌
  제약과 손가락 침투 해석이 충돌). → **IPC 커플러**로 전환(`gs.options.IPCCouplerOptions`).
  단, IPC는 PBD를 못 보므로 봉투 재질을 **`gs.materials.FEM.Cloth`** 로 교체.
- 실측 STL(옆면·바닥이 두께 0으로 핀치된 실링선 포함)을 그대로 넣으면 IPC
  self-intersection sanity check에서 계속 실패. 클리핑/데시메이션 다 시도해도
  실패 지속. **진짜 원인은 위상이 아니라 로그를 올려야 보이는 네이티브 에러**:
  `Geometry(0) in cloth_0_0 is too close (distance=1.2mm, thickness=2mm) to
  Geometry(0) in cloth_0_0` — front/back 패널 간격이 material thickness 대비
  너무 얇아서 생긴 **자기충돌**. 이미 검증된 procedural 5-panel 프록시(간격 6mm)
  로 교체하니 즉시 해결.
- 그리퍼는 6DOF mimic(m0609_rg2_v2.xml) 대신 **단순 2DOF(m0609_rg2.xml)** +
  `set_dofs_position` 텔레포트 사용(IPC의 `two_way_soft_constraint` 가 반력을
  자체 처리, PD 불필요). 결과: `M0609_RG2/grasp_bag_ipc_test.py`, 봉투 Δz +125.8mm.

---

## 6. Tablet

타블렛을 모델링하는 일이 사실상 제일 어렵다고 볼 수 있다.

- Tablet을 모델링하여 샘플백 내에 떨어뜨리는 일이 중요 → **Rigid-PBD coupling**
- 이 문제는 예전에 봉투에 Rigid body 시뮬레이션 시 particle이 찢겨나가거나, rigid body인 알약이 PBD와 닿는 순간 시뮬레이션이 튕겨버리는 현상이 발생했음.
- **따라서 충돌 영역이 사전에 수학적으로 계산되어 있는 방식(예: `Genesis.Entity.box`, `Genesis.Entity.Sphere`)으로 접근하는 것이 좋아 보이는데, 이를 구현하는 방법을 알아야 함.**
- MPM 솔버로 강체 제약을 걸어주는 방식도 생각하고 있어야 할 것 같다. 이전 연구에서는 이런 연구가 존재했나?
- **피로파손 문제** — 압력:

### 6-1. Primitive object 가설과 FEM 적용성

**가설 (내 생각):**
- Rigid body collision에서 사전 작업한 메쉬 파일(**Primitive object** — 충돌 영역을 수학적으로 사전 정의해 두는 방식)이 굉장히 좋은 성능을 보인다.
- 캡슐도 Primitive object로 만들 수 있다면 충돌 성능이 상당 부분 개선될 것이라는 가설. 다만 이 방식이 **FEM에서도 효과적인지는 불분명**하다.

**분석·전략 (Claude):**

1. **Rigid-rigid에서 primitive가 빠른 이유 — 가설 맞음.** Primitive는 충돌 영역이 닫힌 수식(analytic)으로 정의된다. 예: **캡슐 SDF = "선분까지의 거리 − 반지름"** — 곱셈 몇 번. BVH 트리 순회도, 삼각형-삼각형 테스트도 없다. 거리·법선이 **정확**하고 **C¹ 연속**(부드러움)이라 contact normal이 안 튀어 솔버 수렴도 좋고, 닫힌 SDF라 **연속충돌(CCD)·관통 판정**이 쉬워 터널링에 강하다. 메쉬 충돌은 반대(테셀레이션 정밀도 의존, 스텝 사이 빠른 통과를 놓침). Genesis **rigid solver에서 캡슐은 이미 primitive**라 별도 작업이 필요 없다.

2. **FEM 적용성 — 절반만 맞고, 그게 핵심.**
   - **변형체(정제) 자체는 primitive 불가.** FEM의 본질은 표면이 변형장에 따라 매 스텝 움직이는 것이라, 고정된 캡슐/구 수식으로 표현이 불가능하다. FEM 접촉은 **태생적으로 표면 메쉬 기반**(surface vertex/element).
   - **하지만 접촉 쌍의 *rigid 쪽*(plate·공구)은 primitive면 큰 이득.** FEM 표면 vertex ↔ primitive 거리를 analytic하게 계산하면 테셀레이션 없이 정확·저렴·터널링에 강하다.

3. **그런데 Genesis SAP coupler는 이걸 안 한다 — 이게 §7-7 터널링의 구조적 원인.** SAP coupler 구현(`sap_coupler.py`)은 rigid collider를 primitive로 쓰지 않고 **Box plate조차 trimesh → tet 메쉬로 변환**(`mesh_to_elements`)하며, **primitive plane은 명시적으로 금지**(`GEOM_TYPE.PLANE` → raise). 접촉은 `FEMSurfaceTetLBVH` ↔ `RigidTetLBVH`, 즉 **BVH 기반 메쉬-메쉬 이산 접촉**이다. → plate가 한 스텝에 정제 표면 tet 두께를 넘게 움직이면 BVH가 겹침을 놓쳐 관통.
   - 반대로 **IPC는 이 analytic primitive 접촉을 실제로 가지고 있다**(`IPCVertexHalfPlaneNormalContact` = half-plane primitive vs FEM vertex). IPC가 매력적이었던 또 하나의 이유. (단, 현재 RTX 5070에서 Genesis→IPC 경로가 런타임에 죽는 별도 이슈 존재 — §5-1 환경 노트 참고.)

4. **전략 결론.** SAP에 머무는 동안엔 coupler에 primitive를 쓸 수 없으므로, 터널링은 **이산 메쉬 접촉 아티팩트**로 보고 다음으로 누른다: **dt 축소 / substeps 증가**(스텝당 plate 변위 < 표면 tet 크기), **plate 속도 ↓·ramp**, **접촉부 메쉬 세분화**, **plate tet 두께 확보**. primitive contact의 "정답형"은 결국 IPC였다는 점은 기록해 둔다.

### 6-2. SDF vs fan tetrahedralization — 둘은 다른 층위의 방법 (2026-07-14)

§6-1에서 언급한 **SDF(Signed Distance Function)**와, 캡슐 정제를 위해 실제로
구현한 **fan tetrahedralization**(`utills/primitive_tablet_generator.py`)은
이름이 둘 다 "primitive를 수식으로 정의"라서 헷갈리기 쉽지만 **풀고 있는
문제 자체가 다르다.**

**SDF — Rigid(강체) 충돌 전용, 메쉬가 아예 없음.**
- 형상을 `f(x) = (점 x 에서 표면까지의 부호 있는 거리)` 라는 **암시적(implicit)
  함수**로 정의한다. 예: 캡슐 SDF = "선분까지의 거리 − 반지름".
- 정점(vertex)도 삼각형(face)도 없다 — 어떤 점이 형상 안/밖/표면에 있는지,
  법선이 뭔지를 **그 자리에서 수식으로 계산**한다(BVH 순회·삼각형 테스트 불필요).
- **강체 전용인 이유**: 형상이 절대 변형되지 않는다는 전제가 있어야 "표면까지
  거리"라는 하나의 고정된 수식이 성립한다. 정제(FEM)처럼 매 스텝 표면이
  변형장에 따라 움직이는 대상은 애초에 SDF로 표현할 수 없다(§6-1의 결론).
  Genesis rigid solver는 캡슐을 이미 SDF primitive로 취급하므로 이 문제와는
  무관하다.

**Fan tetrahedralization — FEM(변형체) 전용, 실제 메쉬(정점+사면체)를 만듦.**
- FEM은 물질점(material point)이 있어야 변형을 적분할 수 있으므로, SDF 같은
  암시적 표현이 아니라 **명시적 정점 + 사면체(tet) 요소 목록**이 반드시 필요하다.
  일반적으로 이걸 만드는 도구가 TetGen(Delaunay 기반 사면체화 라이브러리)이다.
- **fan tetrahedralization은 TetGen을 안 쓰고 이 정점+사면체 목록을 직접
  계산하는 방법**이다: ①형상의 표면을 파라메트릭 방정식으로 직접 생성(캡슐이면
  원기둥+반구 방정식) → ②**볼록(convex) 도형**이면 내부의 아무 점(보통
  centroid)에서 모든 표면 삼각형으로 부채꼴을 이으면 `tet(a, b, c, centroid)`
  가 항상 유효(퇴화 없음)하다는 사실을 이용 → 표면 삼각형 N개 → 사면체 N개,
  전부 같은 apex(centroid) 하나를 공유. TetGen의 Delaunay 리파인먼트·Steiner
  point 삽입이 전혀 없는, 100% 폐형식(closed-form) 계산이다.
- **한계**: 모든 tet가 같은 apex를 공유하는 구조라, 표면이 급격히 휘는
  영역(캡슐의 극(pole))에 삼각형이 몰리면 그 근처 tet들이 아주 얇고
  뾰족해진다(sliver tet, 종횡비 나쁨) — Delaunay 리파인먼트가 없어서 TetGen처럼
  이런 tet를 자동으로 개선해주지 않는다. §8 캡슐 얼어붙음 조사에서 이게 바로
  캡슐만 불안정하고 Box(sliver 없음)는 안정적인 이유로 좁혀졌다. 또한 오목
  (non-convex) 형상에는 이 방법이 그대로 적용 불가(부채꼴이 형상 밖으로
  나가 tet가 뒤집힘) — 그런 경우는 형상을 볼록 조각으로 나누거나 TetGen처럼
  더 일반적인 사면체화가 필요하다.

**요약**: SDF는 "형상을 수식으로 정의"하지만 메쉬가 없는 강체 접촉 기법이고,
fan tetrahedralization은 "형상을 수식으로 정의"해서 **TetGen을 대체할 메쉬
(정점+사면체)를 만드는** FEM 전용 기법이다. 이름의 "수식적 정의"라는 표현이
같아서 헷갈렸지만 서로 대체재가 아니라 각각 다른 문제(강체 충돌 vs 변형체
메쉬 생성)를 푼다.

#### `gs.morphs.Box`/`Sphere` 는 FEM 에서 primitive 가 아니다 — 실측 재확인 (2026-08-03)

"정제를 Genesis 의 Box 엔티티처럼 primitive 로 만들면 되지 않나"는 질문이
반복해서 나오는데(파일 이름이 `primitive_tablet_generator.py` 라 더 헷갈린다),
**FEM 경로에서는 아니다.** Genesis 1.3.1 에서 직접 측정:

| morph | 입력 형상 | 실제 FEM 엔티티 |
| --- | --- | --- |
| `gs.morphs.Box(size=4.8mm)` | 정점 8 / 면 12 | **정점 9 / tet 12** |
| `gs.morphs.Sphere(r=2mm)` | — | **정점 966 / tet 3791** |
| 우리 해석적 캡슐(§6-2) | — | 정점 137 / tet 288 |

둘 다 TetGen 산출물이다. **1.3.1 에서는 이게 더 분명해졌다** — `genesis/utils/
element.py` 에 `mesh_to_elements` **하나만** 남았고(예전의 `box_to_elements`/
`sphere_to_elements` 는 아예 없어짐), `FEMEntity.sample()` 이 모든 morph 를
동일하게 처리한다:

```
meshes = gs.Mesh.from_morph_surface(morph, surface)   # 형상 → 표면 메시
surface_trimesh = trimesh.Trimesh(...)
verts, elems = eu.mesh_to_elements(surface_trimesh, tet_cfg)   # → TetGen
```

즉 `gs.morphs.Box` 는 "박스 표면 메시를 만들어주는 편의 함수"이지 해석적
primitive 가 아니다. `primitive_tablet_generator.py` 의 "primitive" 도
**"primitive *형상*"(캡슐·박스)** 이라는 뜻이며, 그 파일이 존재하는 이유
자체가 "Box/Sphere 가 FEM 에선 primitive 가 아니더라"는 발견이다.

**Box 를 쓰면 오히려 나쁘다.** 위의 `정점 9 / tet 12` 가 §조합10 에서 파우더
담기가 무반응이었던 원인이다 — 박스 모서리 8개 + 내부점 1개뿐이라 판 중앙처럼
정점이 없는 넓은 영역은 커플링 보정이 전혀 안 된다.

**진짜 primitive 경로는 강체 쪽에만 있다**: MJCF `type="capsule"` geom
(= SDF, §조합6) — `full_workflow_rigid.py` 가 쓰는 방식이다. 정제는 결국
용도에 따라 두 가지 표현이 공존한다:

| | 파일 | 방식 | 진짜 primitive? |
| --- | --- | --- | --- |
| FEM 정제 | `full_workflow.py` | medial-axis 사면체화 → 몽키패치 주입 | ✗ (메시 — FEM 은 원리상 불가) |
| Rigid 정제 | `full_workflow_rigid.py` | MJCF `type="capsule"` | ✓ SDF primitive |

부수 효과: 1.3.1 에서 `mesh_to_elements` 가 **모든 FEM morph 의 단일 관문**이
되면서, §13-9 의 몽키패치가 예전보다 오히려 견고해졌다 — 형상 종류에 따라
다른 함수로 새는 경로가 없다.

### 6-3. Crusher와의 상호작용 — 실측 반력 프로파일 구동 FEM (2026-07-04)

정제가 시뮬 안에서 받아야 하는 힘은 임의 값이 아니라 **실기 Crusher가 실제로 가하는 힘**이다.
이 절은 "Impact plate 접촉이 모델링됐는가?"라는 질문에 대한 답이자, 정제 하중을
실측으로 앵커링하는 현재 방법을 정리한다.

**1) 실기에서 정제가 받는 힘의 정체 — 지령이 아니라 창발.**
크랭크-슬라이더에서 슬라이더가 정제(또는 벽)를 누르는 힘은 `F = τ_crank/(r·sinθ)` 로
기구가 stall 하며 *창발*한다 ([Real2Sim.md](Real2Sim.md) §1). v3 FSM 은
STRIKE(접촉→stall) → RETRACT 사이클을 반복하고, 그 결과가 ForceGage 실측 반력
프로파일(`Crusher_Genesis/Real_result/반력프로파일/{θ}deg.txt`, 5 Hz,
0 → 상승 → stall plateau(~515 N @ 60°) → 해제 → 0)이다. **정제를 두면 부서지기
전까지는 특정 접촉각에서 이 프로파일에 준하는 하중을 받는다**는 것이 대전제.

**2) Impact plate 접촉은 직접 모델링하지 않는다 (못 한다).**
SAP soft contact 는 2 GPa 정제에 하중을 싣지 못하고 plate 가 관통한다(§6-1, §7-7).
그래서 plate–정제 접촉 대신 **타격면 노드를 kinematic Dirichlet 로 구동**한다.
단, 임의 변위 펄스를 주는 것은 물리적으로 무의미하므로 **하중의 크기·시간형상을
실측 반력 프로파일로 강제**한다:

```
① 프로브: 작은 변위 d_probe 압입 → 벽면 σ·n 적분 반력 → 정제 강성 k = F/d 측정
② 실측 프로파일에서 대표 타격 사이클 1개 추출 (peak가 중앙값인 사이클)
③ 피드포워드 d(t) = F_meas(t)/k 로 타격면 구동   ← linear corotated 준정적 → F ∝ d
④ 매 스텝 벽면 반력 F_sim(t) 후처리 → F_meas(t) 와 겹쳐 추종 검증
```

구현: [`Crusher_Genesis/FEM/fem_stroke_real_profile.py`](../Crusher_Genesis/FEM/fem_stroke_real_profile.py).
60° 프로파일 기준 결과: k = 4.41×10⁶ N/m (R4.0/AR1.00/CV0.20, E=2 GPa 가정),
F 추종 RMS 오차 1.4% (peak 515 N). stall plateau 동안 σ_III 압축 기둥과 σ_I
측면 인장 링(균열 핵 후보, §7-8 연계)이 유지되다가 RETRACT 에서 소멸하는
주응력장 시계열을 컷어웨이로 출력한다
(`Sim_result/fem_real_profile_{θ}deg_*_sigI/sigIII_cut.png`).

**3) 가정과 한계 — 해석 시 주의.**
- **프로파일 전이 가정**: 실측은 ForceGage(강체 벽)를 누른 값. 정제가 있으면
  접촉 강성이 낮아져 stall 각도·plateau 힘이 다소 달라질 수 있다. "부서지기 전
  준정적 구간에서는 같은 프로파일을 받는다"는 근사가 대전제.
- **elastic-only**: 파단이 없으므로 515 N 을 끝까지 받는다. 실제 정제는 도중에
  깨진다 — 이 필드는 "깨지기 직전까지의 응력 발달 + 균열 개시 위치(σ_I max)"
  예측용이고, 파단 판정은 §7-4/§7-8 Weibull 캘리브레이션이 담당.
- **E 미캘리브레이션**: 힘은 실측으로 고정되지만 변위(d_max=117 μm @ E=2 GPa)는
  모델 의존. E 를 캘리브레이션하면(§7-8) 변위·강성이 같이 맞는다.
- **접촉 patch 근사**: 타격면 = 상단 10% 노드 band 고정 구속. 렌즈형 정제라
  실제 plate 접촉 patch 와 비슷하지만, Hertz 식 접촉 확장(하중↑ → patch↑)은 없다.

**4) real vs sim 구동 오차 — 트윈은 sim 반력으로 돌아야 한다 (2026-07-04).**
디지털 트윈은 매번 ForceGage 실측이 아니라 **시뮬이 만든 반력**(Crusher_8env.py 의
MuJoCo 벽 반력)으로 검증한다. 그래서 같은 FEM 정제를 real F(t) / sim F(t) 두 프로파일로
각각 구동해 주응력장을 비교했다
([`fem_profile_compare.py`](../Crusher_Genesis/FEM/fem_profile_compare.py),
sim 시계열은 [`extract_sim_profile.py`](../Crusher_Genesis/FEM/extract_sim_profile.py) 로 추출).

- **핵심 관찰 — 3D 필드 오차 = 반력 프로파일 오차로 환원.** linear_corotated 준정적이라
  `σ(x,t) = σ_shape(x)·F(t)/k` — 공간패턴 σ_shape 는 구동원과 무관하게 동일. 그래서
  "3D 응력장을 어떻게 비교하나"는 (A) 시간영역 F·σ_max(t) 겹치기, (B) 공간 Δσ 컷어웨이,
  (C) tet별 σ_real vs σ_sim 산점도(R²·기울기) 3장으로 응축된다.
- **60° 결과**: sim peak 533 N vs real 515 N (+3.5%) → σ_I peak 698→733 MPa (+5.1%),
  필드 rel-L2 오차 4.7%, RMSE 2.2 MPa. **산점도 R²=0.998, 기울기 1.046** —
  즉 두 필드는 거의 완전한 **스케일 복제**.
- **결론**: sim/real 반력 오차는 **파쇄 개시 *위치*(σ_I max 지점)에는 거의 영향이 없고
  *크기*만 ~5% 스케일**한다. 위치 예측(균열 핵)은 sim 구동으로도 견고하고, Weibull
  파단확률(σ 크기 민감)만 반력 캘리브레이션 정확도에 영향받는다.
- **형태 차이 하나 — 해소(2026-07-06).** 종전 sim(Crusher_8env)은 stall 감지 즉시 STRIKE 를
  끊어 **짧은 스파이크(~0.25 s)** 라 real 의 stall dwell(plateau ~1 s) 사다리꼴과 형태가
  어긋났다. `_sim_logged` 에 **stall dwell**(접촉 유지 → plateau, `STRIKE_DWELL_S=1.0 s`
  flat + rise settle ≈4τ)과 **접촉력 1차지연**(`CONTACT_TAU=0.25 s`, rigid-wall 스텝응답
  → 완만한 rise/fall = 정제 탄성변형 근사)을 넣어 sim F(t) 도 **천천히 상승 → dwell → 천천히
  하강** 하는 실측형 사다리꼴이 되게 했다. **peak 캘리브값은 보존** — dwell plateau 를 stall
  검출순간 힘 `Fpk`(= 종전 needle peak)에 고정하므로 low-pass 정상상태 과증(rigid-wall
  674 N)로 새지 않는다. rising-edge 정렬 오버레이(`overlay_60deg_pulse.png`)에서 sim/real
  펄스가 상승슬로프·plateau·peak(525 vs 518 N)까지 거의 겹친다. 준정적·elastic 필드
  비교(σ∝F)엔 무영향, 점탄성/피로 확장 시 dwell 정합만 개선.

**5) 결정 노트 — real vs sim, 무엇으로 FEM을 구동하나 (2026-07-04).**

> **질문**: 실측 반력을 그대로 따라가면 되는데, Real2Sim으로 만든 sim 반력을 따라가는 건
> 오차(+5%)만 얹고 무의미하지 않나?

**결정: real과 sim은 경쟁이 아니라 한 파이프라인의 두 단계다. 측정한 조건은 real,
미측정 조건은 sim.**

| 단계 | 구동원 | 용도 | 근거 |
| --- | --- | --- | --- |
| 앵커·검증 | **real** (ForceGage) | 측정한 조건 (정제 1종·8각도·1 RPM) | real이 있으면 엄밀히 우월. 여기서 sim은 손실 복사본이라 **쓰지 않는다** |
| 예측·생산 | **sim** (Crusher_8env) | 미측정 조건 (새 각도/RPM/공구·온라인 폐루프) | real이 **존재하지 않으므로** sim이 유일한 반력원. 단 검증된 오차범위 내 |

- **측정한 조건에서는 real이 정답이 맞다.** sim은 그 real을 근사한 것이라 +5% 오차만
  더한다. 60°처럼 실측이 있으면 real로 구동한다. — 이 지적은 옳다.
- **트윈의 존재 이유는 "측정 안 한 조건"의 예측이다.** 정제 STL 1000+종·임의 각도·
  다른 RPM엔 따라갈 real 프로파일이 없다. 그 순간 반력을 낼 수 있는 건 시뮬레이터뿐이라,
  sim-driving은 "굳이 sim을 쓰는 것"이 아니라 **real이 없는 곳에서 유일하게 응력장을 내는
  경로**다.
- **§6-3의 real↔sim 비교(4번)는 생산이 아니라 검증이었다.** real·sim이 둘 다 있는 유일한
  케이스(60°)에서 **sim 경로의 오차를 값매김**한 것 = "위치 R²=0.998, 크기 +5%". 이게
  real이 없는 조건에서 sim을 믿어도 된다는 **사용 허가증**이다. 검증 없이 sim을 쓰면 근거가
  없고, real만 쓰면 커버리지가 측정한 8점에 갇힌다.
- **정직한 현재 한계 — sim은 아직 *형상*으로는 일반화 못 한다.** Crusher_8env는 정제 대신
  **강체 벽**을 눌러 F를 뽑으므로, sim의 F는 각도/RPM/stall토크로는 외삽되지만 **정제 형상엔
  반응하지 않는다**(벽이 rigid). 따라서 두 일반화 축의 출처가 갈린다:
  - **반력 F 일반화** → 크러셔 sim (각도/RPM/공구 축) *— 형상은 아직 ✗*
  - **형상별 응력장 σ 일반화** → **FEM** (같은 F를 1000개 STL에 주입 → 형상별 σ)
  → 오늘 기준 sim-driving이 실제로 사주는 값은 **각도/RPM/온라인 폐루프** 축이지 형상 축이
  아니다. 형상까지 sim의 F가 반응하게 하려면 크러셔 sim 루프에 정제 compliance를 넣어야
  하는데, 그게 §6-1·§7-7의 SAP 커플링 문제다.

**스코프 의존**: 만약 이 프로젝트가 측정한 8개 조건만 다루면 되면, sim-driving은 빼고 real만
쓰는 게 맞다. 미측정 조건 예측·온라인 트윈이 목표이면 sim 경로가 필수이고, 그 신뢰도는
위 검증(±5%, 위치 견고)이 보증한다.

**6) 로드맵**: θ = 0~120° 프로파일 8개를 스윕해 각도별 σ_I field → 접촉각이 파쇄
위치·확률에 주는 영향 정량화 → Weibull 파단 모델(§7-4)과 결합.

**7) 준정적 F–θ 반력 캘리브레이션 (Crusher_8env, 2026-07-06).**
§(4)의 60° 단일 각도 필드 비교와 별개로, **여러 접촉각에 걸친 sim 벽 반력의 절대 크기**를
실측 robust-mean에 맞추는 스칼라 보정. 준정적(8 RPM) 운전이라 각 각도의 대표값은 peak
반력 1개로 응축되고([`Crusher_8env.py`](../Crusher_Genesis/Crusher_8env.py), MuJoCo FSM
8-env, N_CYCLES=25 strike의 mean peak), 이를 F–θ 곡선으로 실측과 겹친다.

- **보정 방식 — 원점 통과 최소자승 단일 스칼라.** 물리(각도 의존 형상)는 sim이 내고,
  힘 게인만 한 개 상수로 맞춘다:
  ```
  FORCE_SCALE = Σ(F_sim·F_meas) / Σ(F_sim²)      # 원점 통과 LSQ (각도별 아님)
  ```
  코드에선 스트라이크마다 `Fn = F_raw · FORCE_SCALE · sf`(sf=노이즈)로 적용.
- **105° 제외.** 실측 robust-mean이 394 N 으로 인접 각도(90°=503, 120°=563) 대비 급락 —
  sim 대비 −31%로 다른 각도(±수%)와 성격이 다른 **이상치**라, 스케일 재적합·플롯·`ANGLES`·
  `MEASURED`에서 모두 제거(제거 후 6점으로 재적합).
- **결과: `FORCE_SCALE` 0.98 → 0.9453** (105° 제외 재적합). 각도별 정합:

  | θ [°] | sim (보정) [N] | measured [N] | 오차 |
  |---|---|---|---|
  | 30 | 811 | 896 | −9.4% |
  | 45 | 591 | 596 | −0.8% |
  | 60 | 518 | 515 | +0.5% |
  | 75 | 493 | 456 | +8.1% |
  | 90 | 506 | 503 | +0.6% |
  | 120 | 642 | 563 | +14.0% |

  **평균 절대오차 5.6%.** 중간각(45–90°)은 거의 완전 정합, 양 끝(30°↓·120°↑)은 잔차가
  남는다 — **단일 스칼라는 크기만 맞추지 곡선 *형상*은 못 고친다**(§(4)의 "위치는 견고,
  크기만 스케일"과 같은 성질). 형상까지 맞추려면 각도별 보정이나 위상보정
  `PHASE_OFFSET_DEG`·stall 토크 재튜닝이 필요.
- **출력**: [`Sim_result/sim8env/F_vs_theta_sim.png`](../Crusher_Genesis/Sim_result/sim8env/F_vs_theta_sim.png)
  (y축 0 기준 + measured ±10% 밴드 + 평균오차 주석). robust-mean·스케일은
  [`Crusher_8env.py`](../Crusher_Genesis/Crusher_8env.py) 상단 `MEASURED`/`FORCE_SCALE`.
- **§7-8 재료 캘리브레이션과의 관계**: 이 F–θ 보정은 **하중(반력) 스케일**을 고정하는
  단계로, §7-8이 역보정하는 **재료 항(E·σ_t)** 보다 상류다. σ_I 절대값 = (반력 스케일)×
  (E 스케일)이므로, 여기서 반력을 실측에 앵커해 두면 §7-8의 E·Weibull 역보정이
  반력 불확실성과 분리된다.

---

## 7. FEM 방식으로 모델링

### 7-1. FEM의 대충 정의

**1. 무엇을 푸는가**

연속체(돌, 고무, 살 등)에 힘을 가하면 **모든 점**이 조금씩 움직인다. 이 "모든 점의 변위"를 정확히 풀려면 편미분방정식(PDE)을 무한 차원에서 풀어야 함 — 해석적으로 불가능. FEM은 이걸 **"잘게 쪼개서 근사"로 푸는 방법**이다.

**2. 핵심 아이디어 — "쪼개고, 보간하고, 합친다"**

**3. 풀이 흐름**

```
1. 형상 → tet 메쉬 분할 (전처리)
2. 각 요소의 "강성 행렬" K_e 계산   ← 재료(E, ν)·기하로 결정
3. 전체 행렬 K = Σ K_e 조립
4. 방정식 푼다:  K · u = f
                 ↑   ↑   ↑
              강성행렬 변위 외력
5. u 로부터 변형률 ε, 응력 σ 계산 (후처리)
```

**4. 왜 FEM이 강력한가**

- **임의 형상 OK** — 정사각형이든 정제든 사람 뼈든 메쉬만 만들면 적용.
- **불균질 재료 OK** — 요소별로 다른 E, ν 부여 가능.
- **다물리 결합** — 열·유체·전자기 등 같은 프레임워크에 통합.

**5. 약점 (Genesis 시뮬에서 의미 있는 것)**

- **메쉬 의존성**: 메쉬 거칠면 부정확, 너무 촘촘하면 느림.
- **큰 변형/분할 어려움** — 표준 FEM은 메쉬 토폴로지가 고정. **분쇄(fracture)는 표준 FEM의 한계** — XFEM, eroded element, 또는 MPM 같은 입자법으로 확장 필요.
- **접촉이 까다로움** — 강체-FEM 접촉은 coupler가 따로 처리 (Genesis의 `coupler_options`).

### 7-2. Input 파라미터

| 분류 | 항목 | 단위 | 설명 |
| --- | --- | --- | --- |
| 형상 | mesh (tet) | — | 사면체 메쉬. 표면 STL만 있으면 tetgen으로 자동 생성 |
| 재료 | E (Young's modulus) | Pa | 강성. 클수록 단단 |
| 재료 | ν (Poisson ratio) | — | 옆면 변형 비율 (0–0.5) |
| 재료 | ρ (density) | kg/m³ | 밀도 |
| 경계조건 | fixed nodes (Dirichlet) | — | 못 움직이게 할 노드 |
| 경계조건 | applied force (Neumann) | N | 직접 가할 외력 (Genesis는 rigid 접촉으로 대체 가능) |
| 솔버 | dt, substep | s | 시간 간격 |
| 솔버 | damping | — | 감쇠 (수치 안정성) |

### 7-3. Output 파라미터

| 범위 | 항목 | 단위 | 설명 |
| --- | --- | --- | --- |
| 노드 | 위치 / 변위 u | m | 각 노드가 얼마나 움직였나 |
| 노드 | 속도 v | m/s | 동적 시뮬에서 |
| 요소(tet) | 변형률 ε (tensor) | — | 얼마나 늘어났나 (3×3) |
| 요소(tet) | 응력 σ (tensor) | Pa | 단위 면적당 힘 (3×3) |
| 요소(tet) | Von Mises 응력 | Pa | σ의 스칼라 → 항복 판정 표준 |
| 요소(tet) | 주응력 (principal) | Pa | 최대 인장/압축 |
| 전체 | 반력 (reaction force) | N | 접촉면/고정점에 가해진 힘 → 분쇄력 측정 |
| 전체 | 변형 에너지 | J | 정제에 쌓인 에너지 |
| 전체 | 부피 변화 | m³ | 압축률 |
| **derived** | **균열 핵 위치 (crack nucleation site)** | (tet idx → world xyz) | **`argmax_e σ_I(e)` — 응력 집중부**. 단일 점이 아니라 *상위 N% percentile field* 로 추출하면 weak surface 후보. **pre-fracture 모델링(FEM.md §4.7)의 직접 입력.** |
| derived | 첫 파쇄 시점 t\* | s | `min{t : σ_I_max(t) ≥ σ_t}` — Regime I 의 F_threshold 도출 |

> 충돌된 힘들을 정제에 쌓인 에너지로 사용하고, 이를 N-time과 매칭.
> 균열 핵 위치는 FEM 가 *가장 잘 푸는* 양 (§7-5) — Twin → pre-fractured composite hand-off 의 핵심 인자.

### 7-4. 활용 — 예측과 캘리브레이션

**(a) 예측 (forward simulation)**

실험 전에 새 알약의 **F\* (파쇄 시점)**을 추정. Crusher 운동이 정확하게 모델링됐다면 ±20% 정확도 기대 가능 → 실험 횟수 절약.

> → 이 문제는 알약의 F\*가 이상적으로 한 번에 깨질 때의 이야기이다. 우리가 구해야 하는 건 **W\* (힘의 총량, 면적분)**이다.

**(b) 역추정 / 캘리브레이션 (inverse problem) — 디지털 트윈의 핵심**

실험 데이터(F, hardness)가 있을 때 FEM 시뮬을 fit 해서 **재료 파라미터(E, fracture stress σ_c, plastic threshold)**를 역으로 추출.

#### W\* (cumulative work to fracture) — Twin 레벨에서 측정

사용자의 800N 반복 타격 Crusher에서 F\*의 자연스러운 재정의는 **"몇 번 때려야 깨지나(N_f) + 그때까지의 누적 일(W\*)"**. 단일 임계력 F_threshold는 *재료 물성 파라미터*로 남고, 사용자의 측정·예측 타깃은 **N_f와 W\***가 되어야 함.

#### F\*의 새 정의 (3 후보)

**(a) F_threshold — "이론적 단일 타격 파쇄력" (재료 물성에 더 가까움)**
> "Crusher 한 번의 충격으로 깨려면 필요한 peak force"
- FEM으로 추정: σ_max(F_peak) = σ_t가 되는 F_peak.
- **800N과 비교**해서 regime 판정에 사용.
- 사용자 실험에서는 **간접적**으로만 측정 (사실상 hardness 시험 결과 ≈ F_threshold).

**(b) N_f (cycles to fracture) — "몇 번 때려야 깨지나" ✅ 반복 타격에 가장 자연스러운 정의**
> "800N peak 기준 첫 균열 발생까지의 stroke 횟수"
- 사용자 실험에서 **직접 측정 가능**: 첫 균열 보일 때까지 stroke 카운트.
- FEM + 손상 누적 모델(S-N curve, Paris' law 등)로 예측.
- 단점: Genesis 기본 FEM에는 손상 모델 없음 → 외부 후처리 필요.

**(c) W\* (cumulative work to fracture) — "누적 에너지" ✅ 강력한 대안**
> "첫 균열까지 Crusher가 알약에 전달한 총 일 [J]"
- 정의: `W* = Σ_strokes F(t) · v(t) dt` (각 stroke의 일 합)
- 사용자 실험 측정: torque × angular velocity × time 적분, 또는 reaction force × displacement.
- 재료 물성과 잘 매핑됨 (단위 부피당 fracture energy G_c와 직결).
- **N_f보다 더 본질적** — stroke별 일량 차이를 자동 흡수.

#### Regime 분류

| Regime | 조건 | 거동 | 의미 있는 출력 |
| --- | --- | --- | --- |
| I. 즉시 파쇄 | F_peak (800N) ≥ F_threshold | 첫 stroke에 파쇄 | F_threshold (전통적 F\*) |
| II. 누적 손상 | F_peak < F_threshold 이지만 σ_max > σ_t·k | 여러 stroke 누적 후 파쇄 | N_f, W\* |
| III. 영구 안 깨짐 | F_peak < critical & σ_max ≪ σ_t | 깨지지 않음 | (해당 알약 분쇄 불가) |

- **Pre-fractured rigid composite** — 정제를 미리 여러 rigid 조각으로 만들고 weak constraint로 묶어, 응력 한계를 넘으면 constraint를 끊기. Genesis 안에서 hack으로 구현 가능.

### 7-5. 왜 1차 파쇄는 FEM이 맞나

- 1차 파쇄 직전까지 정제는 **연속체** — continuum 가정 유효.
- 균열 *핵*의 위치/시점은 **응력 집중부**에 의해 결정 — FEM의 응력장 분해능이 높음.
- 1차 분쇄력(F\*)은 **재료 강도 + 형상**의 함수 — FEM의 변동성(E, ν, σ_t)와 직접 매핑.

**MPM이 1차 파쇄에 약한 이유:**
- 입자 단위라 응력장이 **공간적으로 노이지** — 균열 핵 위치 부정확.
- 강성 계산이 부드러워서(smoothed) **임계 응력 도달 시점**이 모호.
- 큰 변형/유동 시 그 진가 발휘 — 1차 파쇄 전엔 과한 모델.

### 7-6. 워크플로우

```
[새 알약 도착]
   │
   ▼
[측정] shape (3D scan), mass, curvature, hardness
   │
   ├─→ ρ = mass/volume                  (직접)
   ├─→ σ_c ≈ Hardness / 접촉면적          (직접 추정)
   ├─→ literature: E, ν, σ_t 표준값        (정제 종류 알면)
   │
   ▼
[FEM 1차 시뮬] (literature 값으로) → 예측 N_f_sim, W*_sim
   │
   ▼
[Crusher 실험 1회] N_f_meas, W*_meas 측정
   │
   ▼
[캘리브레이션] σ_t·E 조정 → 시뮬 ≈ 실험 매칭
   │
   ▼
[검증된 material card] 저장
   │
   ▼
[새 형상 (같은 처방) 들어옴] → Forward 예측만, 실험 생략 가능
```

### 7-7. 접촉 모델링 주의 (Rigid–FEM)

→ Rigid plate가 FEM tablet을 누를 때, **표면 노드의 위치**만 보고 contact pair를 만들어 force를 인가한다. 내부 노드는 이웃 element의 strain 변화로 *간접* 전달.

**(1) Tunneling (관통) — 가장 흔한 문제**

Rigid가 빠르게 움직이면 한 step 동안 표면 vertex 사이의 공간을 *건너뛰어* 내부로 들어옴. 표면 노드 충돌 없으면 → contact 미감지 → rigid가 FEM 내부로 박힘.
- **예방**: `dt` 작게, rigid 속도 제한.

**(2) Sparse mesh에서 정확도 손실**

표면 vertex가 듬성듬성하면 vertex 사이의 face 중간으로 rigid가 닿아도 충돌 안 잡힘. **소형 rigid + 듬성한 FEM mesh**가 위험.
- **예방**: tet 메쉬 더 촘촘하게(`scale` 줄이기, tetgen 옵션). 정제의 경우 12,892 tet 정도면 일반적으로 OK.

**(3) Rigid plate 구동 — `set_pos` 금지, velocity control 사용**

Rigid plate를 일정 속도로 누르려고 매 step `set_pos`로 위치를 강제 텔레포트하면 **반드시 계산 문제가 생긴다**:

- `set_pos`는 **이산적(hard) 위치 덮어쓰기** — 속도/가속도와 일관성 없음. 솔버 내부 상태(rigid mass, momentum, contact predictor)가 그 점프를 *연속적인 운동*으로 해석하지 못함.
- SAP coupler 입장에서 plate 속도가 0 (또는 정의되지 않음) → contact 임펄스를 보내지 않다가 penetration이 깊어지면 한 번에 큰 임펄스 폭발 → 정제 튕김 → 또 무접촉 → spike만 반복되는 *불연속 contact 거동*.
- 시각적으로는 plate가 FEM mesh를 *통과*하는 것처럼 보임 (Genesis FEM 정제 + 1 μm 두께 compression 케이스에서 확인됨, 2026-06-29).
- 게다가 `set_pos` 직후의 한 step 사이에 외력(중력 등)이 누적되면 의도한 속도의 1000× 노이즈가 끼어 더 망가짐.

**원칙**: rigid plate든 grinder의 driver든, **운동학적으로 움직여야 하는 강체는 control_dofs_velocity (Genesis) 같은 PD-controlled velocity target을 써야** 솔버가 운동을 *연속적인 속도장*으로 인식하고 contact impulse도 매 step 정상적으로 흐른다. position 제어가 정말 필요하면 prismatic joint + velocity control로 우회.

(이 교훈은 §3 Crusher 의 "velocity control" 권고와 같은 맥락 — *position 강제는 closed loop든 single body든 항상 깨진다*.)

### 7-8. 한 알약 예시 — 캘리브레이션 워크플로우 (worked example)

§7-4·§7-6을 **구체 수치**로 굴린 예. 대상: 원형 biconvex 정제
`tablet_R4.0_AR1.00_CV0.20` (지름 D=8 mm, 전체두께 t=3.5 mm, 밴드 W=2 mm,
≈200 mg, MCC 주성분).

**용어 — "조정 항" vs "맞춤 표적"** (이 구분이 캘리브레이션의 핵심)

| 구분 | 정의 | 예 |
|---|---|---|
| **캘리브레이션 항 (조정)** | 몰라서 돌려 맞추는 미지 파라미터 | **E**¹, ν, (σ_t), Weibull m, ~~G_c~~², **손상규칙 계수**, 접촉/봉투/전류 |
| **표적 (맞춤)** | 실험으로 재서 트윈이 재현해야 하는 출력 | F(δ) 곡선, Brazilian σ_t, **F_peak–N_f**, 균열위치 |

> **N_f·W\* 는 항이 아니라 표적**이다. σ_t·손상계수(항)로부터 *예측*하고, 실측 N_f에
> 맞춰 계수를 조정한다 (DataInventory.md §E-3와 동일 구조).

**¹ E는 "조정 항"이 아니라 장비에 따라 "입력"으로 격상된다.** E를 직접 재는 "E 미터기"는
없다 — 어떤 장비든 F(δ) 곡선을 재고 *모델로* E를 역산할 뿐이다. 따라서 성격이 갈린다:
- **UTM + 규칙 시편**(평면 compact·굽힘 beam): 곡선→E가 닫힌 공식(`σ=Eε`) → **직접
  측정 → 입력으로 고정**(강한 prior). STEP 2 역보정 불필요.
- **통짜 biconvex 정제만**: 곡면 Hertz 접촉 탓에 닫힌 공식 없음 → **FEM back-fit**으로만
  E를 뽑음 → *이때만* E가 "조정 항"으로 남는다(STEP 2).
- **UTM 없음**: E를 문헌값(MCC ~4–9 GPa)으로 고정 → 아래 **저자원 경로**.

**² G_c 는 목록에 있으나 실제로는 W\* 로 대체한다.** G_c 는 *단위 균열면적당* 에너지
[J/m²]라 총량 환산에 균열 면적 A가 필요(`W=G_c·A`). 깨끗한 1개 균열이면 A≈단면적으로
가능하지만, **가루 분쇄는 새 표면적 A가 방대·측정 불가**(분쇄공학 Rittinger/Bond 법칙이
이 때문에 존재). → 트윈은 G_c·A 대신 **바깥에서 잰 일 `W*=∮F·v dt`** 를 직접 표적으로
삼아 우회한다(§7-4).

**주응력장(σ_I)과 σ_t의 역할**
- σ_I = 각 점에서 전단이 0인 3개 주축의 수직응력 중 최대(가장 인장쪽). σ_I 장 =
  **인장 집중 = 균열 개시 위험 지도**.
- 취성 파괴는 최대 인장 주응력이 구동(Rankine): **σ_I ≥ σ_t 이면 그 자리에서 균열**.
- σ_I **방향·상대분포**는 노드 변위만으로(물성 없이) 나온다. **절대값[MPa]** 만
  E(스케일)+ν(텐서 혼합) 필요 → 값이 없으면 실측 힘으로 E를 역보정.
- **파쇄에 직접 관여하는 물성은 σ_t(저항) 하나, 구동자는 σ_I(하중).** E·ν·형상은
  σ_I 를 *만드는* 간접 인자(하중→σ_I "환율")일 뿐 파쇄 판정 자체엔 관여 안 한다.

**STEP 0 — 형상 → 메쉬**: STL → tet 분할 (예: 노드 2745, tet 12005).

**STEP 1 — 실험으로 표적·입력 수집**

| 시험 | 결과 | 용도 |
|---|---|---|
| 단축 압축 F–δ | 힘–변위 초기 기울기 | → E (규칙 시편이면 직접, 통짜면 back-fit 표적) |
| Brazilian(직경압축) = **정제 경도계** | F_break = 80 N | → σ_t (Pitt 식, **E 불필요**) |
| 위 30개 반복 | 파괴하중 분포 | → Weibull m ≈ 8 |
| Crusher 반복 타격 | F_peak별 파쇄 타수 | → F_peak–N_f 표적 (=취득 가능한 핵심 실측) |

볼록면이라 σ_t 는 **Pitt 식**:
`σ_t = 10F/(πD²)·[2.84·t/D − 0.126·t/W + 3.15·W/D + 0.01]⁻¹ = 800/(π·64)/1.82 ≈ 2.2 MPa`

**STEP 2 — E 확정**: *장비에 따라 경로가 갈린다(각주 ¹).*
- **규칙 시편 UTM 있음** → `σ=Eε` 로 E를 직접 읽어 **입력 고정** (이 STEP은 측정 1줄로 끝).
- **통짜 정제만**(이 예시) → **FEM back-fit**: 강제변위 FEM 반력 F(δ)를 실측 기울기에 맞춰
  E 조정. 가정 E=2 GPa → 반력이 실측의 1/3 → **E ≈ 6 GPa** 로 수렴(MCC 현실값), ν=0.25
  문헌 고정.

이제 σ_I 절대값[MPa]이 물리적 의미를 가진다.

**STEP 3 — 단일 타격 σ_I → σ_t 판정**: 보정된 E로 한 타격의 σ_I 장 계산 →
σ_I,max ≥ σ_t(2.2 MPa)이면 그 지점 1타 파쇄, **F_threshold** 산출 + 균열 개시 위치
확정. 미달이면 STEP 4.

**STEP 4 — 손상누적 → N_f 예측 (2순위 항)**:

> **σ_I 는 매 타격 올랐다 내려오는 *순간값*(타격마다 리셋), 누적되는 건 손상 `D`다.**
> σ_I 는 매 타격 D 를 *얼마나 늘릴지* 정하는 입력일 뿐 자신이 쌓이지 않는다.

손상변수 `D ∈ [0,1]` (0=온전, 1=파쇄). 매 stroke i 의 peak σ_I 로 증분을 더한다:

`D = Σ_i ΔD_i,   ΔD_i = (σ_I,i / σ_t)^p,   D ≥ 1 → 파쇄 (그때 타수 = N_f)`

- **σ_I ≥ σ_t** → ΔD ≥ 1 → **1타 파쇄** (Regime I)
- **σ_I ≲ σ_t** → ΔD < 1 누적 → **N_f 타에 파쇄** (Regime II)
- **σ_I ≪ σ_t** → ΔD ≈ 0 → **안 깨짐** (Regime III)

지수 하나(p)로 세 Regime 이 연속적으로 갈린다. **손상규칙 계수 = p**(문턱하 민감도;
subcritical crack growth·Weibull 유래)를 실측 F_peak–N_f 곡선에 맞춰 조정(예: 60 N 예측
5 → 실측 3 에 수렴). Weibull m 은 파쇄 *확률* 산포로 반영.

> **Weibull 파괴확률은 스칼라가 아니라 σ_I *장(field)* 의 부피적분이다** (약한 고리):
> `P_f = 1 − exp[−∫_V (σ_I(x)/σ_0)^m · dV/V_0]` (σ_I>0 인장부만). FEM 에선 **tet 별
> σ_I·부피 합산**(risk of rupture). peak σ_I 하나만 쓰면 유효부피 `V_eff/V_0` 인자를
> 빠뜨린 근사다. σ_0 = 특성강도(63.2% 파괴 응력). 수식 PNG: [`Notation.py`](Notation.py)
> (`weibull_pf`·`weibull_fem_sum`·`weibull_veff`).
- **누적일 `W = Σ∫F·v dt`** (토크×각속도 or 반력×변위) — **실측 가능**. 에너지형 손상
  `D = W/W*` 와 직결(§7-4 W\*). ⇒ 트윈은 σ_I→D 로 *예측*, 실기는 W 로 *관측*해 맞춤.
- **강성 저하**: 손상↑ → 정제 물러짐 → stroke 당 슬라이더 관통량↑ / 반력 기울기↓.
- **AE(음향방출)**: 미세균열 이벤트 카운트.
- **FSM "stall 없이 통과"**(Crusher.md §12-4) = D 가 1 도달한 순간 = **N_f 온라인 검출**.

**STEP 5 — 검증 & 사용**: 보정에 안 쓴 F_peak(예: 75 N)로 N_f 예측 vs 실측 검증.
실기 FSM은 "stall 없이 통과"로 N_f를 온라인 카운트(Crusher.md §12-4) → A열 실측
피드백. 검증되면 **실험 없이** 신규 형상(CV/AR 스윕)·타격 스케줄의
N_f·필요토크·균열패턴을 예측한다.

**한 장 요약**

| 역할 | 항목 |
|---|---|
| 입력(측정) | σ_t=2.2 MPa, Weibull m≈8, ρ·porosity, (**E**: UTM 규칙시편 있으면 여기로) |
| 조정 항 | **손상규칙 계수**(F_peak–N_f로) — 순수 미지항은 사실상 이것뿐. **E**는 통짜 정제일 때만 F–δ back-fit(≈6 GPa). ~~G_c~~→W\* |
| 표적(맞춤) | F(δ), Brazilian σ_t, F_peak–N_f, 균열위치 |
| 출력(예측) | 신규 조건 N_f · 필요토크 · 균열패턴 |

> 한 줄: **손상계수는 "돌려 맞추는 항", σ_t는 "재서 넣는 입력", N_f는 "예측·검증
> 표적"** — E는 장비가 좋을수록 조정 항→입력으로 격상된다. 세 역할이 한 알약을 관통한다.
> 관련: [`fem_stress_field.py`](../../Crusher_Genesis/FEM/fem_stress_field.py), DataInventory.md §E.

**저자원 경로 (경도계 + Crusher 만 있을 때)** — UTM·별도 Brazilian 없이 대부분 커버된다:
- **경도계 = 직경압축 = Brazilian.** 파괴하중 `F_break` 를 재고 → **Pitt 식으로 σ_t 도출
  (E 불필요, 순수 기하 공식)**. 전용 UTM Brazilian 을 따로 할 필요 없다.
- **같은 경도계로 30개 반복** → 파괴하중 분포 → **Weibull m** (취성 강도 산포).
- **Crusher F_peak–N_f** → 손상규칙 계수 fit(STEP 4). F_peak–N_f 자체가 Crusher 로 얻는 값.
- ⇒ **경도계 하나로 σ_t · (F_threshold ≈ 경도) · Weibull m 을 얻고, 순수 조정 항은 손상계수
  하나로 줄어든다.**
- **E 는 언제 필요?** *단일 파쇄력엔 불필요* (F_threshold ≈ 경도). E 는 **균열 *위치* 와
  N_f(반복 손상누적)** 를 풀 때만 추가로 든다 → 없으면 문헌값(MCC ~4–9 GPa)으로 고정.
- **잃는 것**: σ_I 절대값이 문헌 E 의존 → 균열 위치·F_threshold 정밀도↓. 하지만 N_f 경로
  (Regime II)는 fit 이 스케일 오차를 흡수해 **성립**한다.
- 한 박사님 피드백 "Data-driven 하게라도 풀 수 있어야"(§10)에 정확히 대응.

---

## 8. 발생할 수 있는 문제 사항

- 실제 운용 속도와 맞을지는 의문.
- 파지할 때 마찰과 파지력으로 집는 것이 아님 → **weld**.
- 샘플백의 파라미터를 튜닝하는 일이 필요.
- **[미해결] implicit FEM 솔버가 정지 상태(v=0)에서 중력을 무시하고 얼어붙음**
  (`FEM/fem_tablet_drop.py`, 2026-07-13 격리 확인). 초기 속도 킥으로 우회
  시도했지만 형상에 따라 필요한 킥 크기가 다르고, 통하는 경우도 비물리적
  거동(찌그러졌다가 중력 반대로 상승)을 보임. Rigid 엔티티가 씬에 있으면
  킥을 줘도 다시 얼어붙음 — 원인 미상, Genesis 쪽 확인 필요.
- **[해결] FEM.Elastic + M0609(IPC) 조합 "낙하 얼어붙음" — 원인 확정 (2026-07-14)**
  (`M0609_RG2/grasp_bag_tablet_ipc_test.py`, `utills/primitive_tablet_generator.py`).
  `fem_options`에 `use_implicit_solver=True`를 안 주면(기본값) 1차 문제는
  해결되나, M0609가 씬에 있으면 FEM.Elastic이 다시 거의 얼어붙는 2차 문제가
  있었다. 처음엔 "정점/tet 개수 임계치" 가설을 세웠으나(`gs.morphs.Box`는
  정상, `Sphere`/정제 STL은 얼어붙음), **박스 적층(5-layer→3-layer, tet 수를
  오히려 줄임)으로 반증됨** — 3-layer가 5-layer보다 더 심하게 얼어붙어 단순
  개수 비례가 아님을 확인.
  **진짜 원인**: 정점/tet 개수가 아니라 **TetGen을 거쳤는지 여부 자체**였다.
  `genesis/utils/element.py`의 `box_to_elements`/`sphere_to_elements`/
  `mesh_to_elements` 는 전부 `mu.tetrahedralize_mesh`(TetGen)를 호출하는데,
  `gs.morphs.Box`만 우연히 안전한 게 아니라 **TetGen이 Box처럼 아주 단순한
  볼록 입력에 한해 "질 좋은/안전한" tet를 내놓고, 조금만 복잡해지면(Sphere,
  실제 메시) M0609+IPC 커플링과 상호작용하는 무언가 다른 내부 상태를 만드는
  것**으로 좁혀졌다.
  **검증**: `utills/primitive_tablet_generator.py` 로 캡슐을 **TetGen을 전혀
  거치지 않고** 순수 수학적으로 사면체화했다 — 캡슐 표면을 파라메트릭
  방정식으로 직접 생성하고, 볼록 도형의 정석 기법인 **centroid fan
  tetrahedralization**(모든 표면 삼각형을 중심점과 이어 사면체 하나씩,
  `tet(a,b,c,centroid)`)으로 verts/elems를 직접 계산한 뒤,
  `genesis.utils.element.mesh_to_elements`를 몽키패치해 TetGen 경로를
  건너뛰고 Genesis에 직접 주입했다(Genesis FEM solver는 `det([a-d,b-d,c-d])
  < 0` 방향성 요구 — 위반 시 `RuntimeError: tet_wrong_order`, 삼각형별로
  부호 확인 후 필요시 정점 swap으로 해결). **이 완전 비-TetGen 캡슐(정점
  83개, tet 160개)은 M0609 앞에서 얼어붙지 않고 정상 낙하 →
  파지→리프트까지 전 구간 성공**(tablet Δz=+123.2mm, Box 근사(+117.6mm)와
  거의 동일) — **TetGen 산출물 자체가 원인이라는 가설이 최종 확인됨**.
  실용적 해결책: Box primitive 근사, 또는 정확한 형상이 필요하면
  `primitive_tablet_generator.py`의 analytic fan-tetrahedralization 사용
  (단, 볼록 도형에만 적용 가능 — 오목 형상은 centroid fan이 무효가 되므로
  별도 분해 필요).

- **[정정 + 신규 발견] "TetGen 산출물이 원인"은 M0609 케이스에 한정 —
  FEM.Elastic(체적) + FEM.Cloth(표면 전용) 조합은 별개의 얼어붙음 버그
  (2026-07-14, `FEM/fem_tablet_drop.py`)**: 위 결론(TetGen 산출물 자체가
  원인)은 M0609 로봇이 있는 씬에서만 검증됐다. 정제를 실제 샘플백
  (FEM.Cloth)에 낙하시키는 씬에서 재테스트한 결과, **TetGen 을 전혀 안 쓴
  analytic 캡슐도 FEM.Cloth 봉투가 씬에 있으면 접촉 여부/거리(멀리 떨어뜨려도
  동일)/속도 킥과 무관하게 거의 완전히 멈췄다** — 심지어 봉투를 Rigid 메시로
  바꿔도 재현됨. 반면 **`gs.morphs.Box` primitive 는 이 조합에서도 예외적으로
  안정적**(격리 테스트: t=50ms 에 120→106.5mm, 이론 자유낙하와 근접). 즉
  "TetGen 산출물"과 "Box 냐 아니냐"는 서로 다른 두 얼어붙음 버그 각각에서
  독립적으로 확인된 회피 조건이며, 근본 원인(체적 FEM 대 표면 전용 FEM
  결합 시 IPC 솔버 내부에서 무엇이 문제인지)은 아직 미상이다 — Box
  primitive 만이 현재까지 발견된 두 버그 모두에서 안정적인 유일한 형상.
  추가로 확인된 특이사항: 봉투 입구 통과 여부가 knife-edge 조건이라
  `contact_d_hat=1mm` 에서는 동일 설정으로도 실행마다(GPU 부동소수점
  비결합성 추정) 통과/걸림이 갈렸고, `contact_d_hat=0.5mm` 로 낮추자
  안정적으로 통과함(실측 2/2).

- **[변인통제 실험] 캡슐 얼어붙음의 원인은 "우리 수식 정의 방식"이 아니라
  "캡슐이라는 형상/토폴로지" — Box 대조군으로 확정(2026-07-14)**: 위 발견에서
  "analytic 캡슐도 FEM.Cloth 봉투 앞에서 얼어붙는다"까지만 알았고, 이게
  ①우리가 만든 TetGen 우회 방식(표면 직접 계산 + centroid fan
  tetrahedralization + `mesh_to_elements` 몽키패치 주입) 자체의 결함인지,
  아니면 ②캡슐이라는 형상 고유의 문제인지가 불분명했다. 변인통제:
  **`Samplebag(FEM.Cloth) + 우리 방식으로 만든 analytic Box(FEM.Elastic,
  정점 9개/tet 12개, `primitive_tablet_generator.make_box_tets`)`** 를
  `Samplebag + gs.morphs.Box`(대조군, TetGen 경유하지만 이미 안정성 확인됨)
  와 비교 — **거의 완전히 일치하는 정상 자유낙하**(t=50/100/200ms 에서
  106.55/68.62/-81.10mm vs 대조군 106.52/68.56/-81.70mm). 즉 **우리의 수식적
  형상 정의 방식 자체는 정상**이고, 캡슐만 얼어붙는 원인은 ②쪽 — 구체적으로는
  **fan tetrahedralization이 극(pole) 근처에서 만드는 다수의 얇은 sliver
  tet**(하나의 centroid 정점을 공유하는 부채꼴 구조상, 표면이 급하게 휘는
  영역에 삼각형이 많이 몰리면 종횡비 나쁜 tet가 다수 생김 — 해상도를 올렸을
  때 실제 좌굴 변형으로 관찰된 것과 동일 메커니즘)로 좁혀졌다. Box(12개,
  종횡비 좋음)는 문제없고 캡슐(160개, 극 근처 sliver 다수)만 얼어붙는 것과
  일치. **SDF(§6-1 참고)와는 무관** — SDF는 애초에 FEM(변형체)에는 적용 불가한
  Rigid 전용 접촉 표현이라, 이번 fan tetrahedralization 접근과는 완전히
  다른 층위의 방법이다(아래 §6-3 참고).

  **참고**: Box와 캡슐은 **둘 다 볼록(convex)** 이라 fan tetrahedralization
  자체(사면체 유효성)는 둘 다 성립한다 — 문제는 볼록성이 아니라 "전역
  centroid 하나로부터의 거리가 표면 전체에서 균일한가"였다. Box는 8개
  꼭짓점이 중심에서 대략 비슷한 거리(반대각선 절반)에 있어 12개 tet의
  종횡비가 고르지만, 캡슐은 극(pole) 쪽 작은 삼각형까지 전부 반지름보다
  훨씬 먼 전역 centroid(예: 반지름 2.5mm인데 극-centroid 거리 6mm)로
  이었던 게 문제였다 — 형상의 "볼록/오목"이 아니라 "부채꼴에 쓰는 apex와
  표면 사이 거리의 균일성"이 sliver 발생 여부를 결정한다.

- **[해결] sliver 없는 캡슐 사면체화 — medial-axis 다중 앵커 방식
  (2026-07-14, `utills/primitive_tablet_generator.make_capsule_tets_v2`)**:
  위 sliver 원인 분석을 그대로 뒤집어 해결책으로 썼다. 캡슐의 수학적 정의
  자체가 "중심 선분(medial axis)까지 거리 ≤ 반지름인 점의 집합"이므로(§6-2
  SDF 설명과 동일한 정의), 전역 centroid 하나 대신 **표면의 각 부분을 그
  지점에서 가장 가까운 축 위의 점에 부채꼴로 잇는다**:
  - 북/남 반구(뚜껑)는 정의상 그 반구 자신의 중심점에서 항상 정확히
    반지름 R 만큼 떨어져 있으므로, 반구 표면 전체(pole 포함)를 그 반구
    중심 하나로 부채꼴 — apex-표면 거리가 어디서나 정확히 R로 균일해짐.
  - 원기둥 몸통은 `n_cyl_bands` 개 층으로 나누고, 각 층 경계를 표준
    "삼각기둥→3-사면체" 분해(널리 쓰이는 프리즘 메싱 기법)로 처리 — 인접
    층/반구가 같은 앵커점을 공유해 내부 경계면이 정확히 상쇄되어(watertight)
    유지된다(직접 검증: 축퇴(0에 가까운 부피) tet 0개, 전체 부피가 이론값에
    근접).
  - **결과(실측)**: 최대 edge-길이비(sliver 정도 지표)가 **15.0 → 6.25로
    개선**(같은 n_theta/n_cap_rings). 바닥 낙하 테스트에서 착지 후 좌굴/찌그러짐
    없음(v1은 해상도를 올리면 좌굴 발생했었음). **더 중요하게, M0609+FEM.Elastic
    얼어붙음과 FEM.Cloth+FEM.Elastic 얼어붙음 둘 다에서 더 이상 얼어붙지
    않고 Box와 거의 동일한 정상 자유낙하를 보임**(Cloth+캡슐 v2:
    t=50/100/150/200ms 에 107.5/70.7/9.5/-76.1mm — Box 대조군 106.5/68.6/6.3/
    -81.1mm 과 거의 일치). 봉투 통과 데모(§Tablet)에서도 실제로 입구를
    통과해 내부까지 안정적으로 낙하함을 확인(contact_d_hat=0.5mm).
  - **함의**: 이번 결과로 앞서 별개로 보였던 두 얼어붙음 버그(M0609+TetGen
    산출 메시, FEM.Cloth+FEM.Elastic)가 사실 **같은 근본 원인(FEM 메시의
    tet 종횡비/조건수 불량, 즉 sliver tet)에서 비롯된 동일 계열의 문제였을
    가능성이 높다** — "TetGen이냐 아니냐", "Cloth가 있냐 없냐" 는 진짜
    원인이 아니라, 그 조건에서 우연히 sliver가 있었는지 없었는지의 대리
    지표(proxy)였던 것으로 보인다. Box가 두 버그 모두에서 예외적으로
    안정적이었던 이유도 이걸로 설명된다(sliver가 없는 형상이라서).

- **[해결(가설)] Rigid(정제, MJCF capsule geom=SDF) + FEM.Cloth(봉투) + IPC
  조합 접촉 시 발산 — `coup_type` 자동선택 문제로 특정(2026-07-14/15)**
  (`FEM/rigid_capsule_tablet_bag_ipc_test.py`): §6-1에서 제안한 "정제를
  sliver 없는 tet mesh 대신 Rigid MJCF capsule(네이티브 SDF primitive)로
  넣으면 어떨까"를 실제로 시도한 첫 버전은 접촉 순간 위치가 수 미터로
  튕겨나가는 발산을 보였다(`constraint_strength` 100→0.5로 낮추면 발산은
  막히지만 감쇠 없는 바운스가 지속 — 원인 미상으로 보류됨, git 3fca8c8).
  **재조사 결과**: `genesis/engine/couplers/ipc_coupler/coupler.py`
  `_setup_coupling_config`(L206-215)의 `coup_type` 자동선택 규칙은
  `entity.n_joints > 0`(관절 있음)이면 `two_way_soft_constraint`(Genesis
  rigid solver의 PD/제어 결과를 IPC가 soft constraint로 따라가게 하는
  방식 — **제어 대상(로봇 팔 등)을 위한 경로**), `n_joints == 0`(무관절
  단일 바디)이면 `ipc_only`(IPC가 중력·동역학을 전부 담당하는 one-way
  경로 — Plane/Shelf가 쓰는 경로)를 쓴다. 이전 시도는 캡슐을 MJCF
  `<freejoint/>` 바디로 만들었으므로 `n_joints=1`→자동으로
  `two_way_soft_constraint`를 탔을 것으로 추정된다. 이 정제는 PD로
  구동되는 제어 대상이 아니라 **순수 낙하하는 수동체**이므로 의미상
  맞지 않는 경로였다는 가설.
  **검증**: 동일한 MJCF capsule(freejoint 유지, `n_joints`는 그대로
  1)에 `material=gs.materials.Rigid(coup_type="ipc_only", ...)`로
  자동선택을 **명시적으로 override** — Plane/Shelf에 이미 검증된 경로를
  강제 적용. 결과: **발산 없이(300 스텝 끝까지 `|pos|<1m` 유지) 정제가
  봉투 입구(105mm)에서 낙하해 봉투 바닥 근처(≈15.9mm)까지 자연스럽게
  안착**(`net_fall=101.28mm`, xy는 봉투 중심 근방 유지) — 영상으로도
  좌굴/폭발 없이 봉투 안에 담기는 모습 확인
  (`rigid_capsule_tablet_bag_ipc_ipc_only_20260714_202712.mp4`).
  **주의**: 이건 "재현 1회 성공"이며 근본 원인이 100% 확정된 건 아니다
  (`two_way_soft_constraint` 자체가 원리적으로 왜 무제어 낙하체에서
  발산하는지는 아직 코드 레벨로 추적 안 됨 — 후속 조사 항목으로 유지).
  다만 실용적으로는 **무관절/무제어 Rigid 낙하체는 `coup_type="ipc_only"`
  를 항상 명시하라**는 지침으로 채택할 만하다.

- **[성공 + 신규 한계 발견] FEM(정제, sliver-free v2 캡슐) + FEM.Cloth(봉투)
  강성 상향 스윕 — 200x(E=1e7)까지 안정, 2000x(E=1e8)에서 새로운 "중력
  무시" 현상 재현(2026-07-15, `FEM/fem_tablet_drop_stiff.py`)**: 위 Rigid
  캡슐 경로는 정제를 강체로 근사해 압축·변형 거동을 볼 수 없다는 한계가
  있어, **FEM(정제)+FEM(봉투)** 조합을 유지한 채 fem_tablet_drop.py의
  "안정성 우선으로 낮춘 E=5e4"보다 강성을 올려 재도전했다.
  **dt 스케일링**: explicit FEM의 안정 dt는 파동속도 c=√(E/ρ)에 반비례하므로
  `dt_new = dt_base·√(E_base/E_new)`로 스케일링(기준: E=5e4, dt=5ms → 검증됨)
  하고, 물리 시간(1.5s)이 유지되도록 스텝 수도 같이 늘렸다.
  - **E=1e6(20x, dt=1.12ms, 1342 스텝)**: 발산 없음. 정제가 봉투 바닥
    근처(z≈19mm)까지 정상 낙하·안착. 형상 유지 양호(z_span 4.438→4.509mm,
    거의 불변 — 무른 재질(E=5e4)보다 훨씬 "딱딱한 정제"다운 거동).
  - **E=1e7(200x, dt=0.354ms, 4243 스텝)**: 마찬가지로 발산 없음, 더 나은
    형상 유지(z_span 4.639→4.675mm). 영상으로 봉투 안 안착 확인
    (`fem_tablet_bag_drop_stiff_E1e+07_*.mp4`).
  - **E=1e8(2000x, dt=0.112ms, 13416 스텝)**: **정제가 사실상 전혀
    낙하하지 않음**(1.5초 시뮬 동안 net_fall=0.007mm, 봉투 입구조차 통과
    못함) — §8 위쪽에 이미 기록된 "[미해결] implicit FEM 솔버가 정지
    상태에서 중력을 무시하고 얼어붙음" 버그와 증상은 동일하지만, 이번엔
    `fem_options`를 전혀 건드리지 않은 **기본(explicit) 솔버**에서
    재현됐다는 점이 다르다 — 즉 원인이 "implicit 솔버 특정"이 아니라
    더 일반적일 가능성. **가설**: 이 정제(mm 스케일, 부피 ~수 mm³)의
    중력(F=mg)은 애초에 극히 작은 값(~1e-7N 수준)인데, E=1e8처럼 강성이
    극단적으로 크면 부동소수점 잔차 수준의 미세한 변형만으로도 이를
    상쇄하는 내부 탄성력이 발생해, 매 스텝 중력이 수치적으로 묻혀버리는
    "강성-질량 불균형" 수치 문제로 추정(코드 레벨 확정은 안 됨, 후속
    조사 필요).
  - **결론**: 이 dt 스케일링 방식으로는 **200x(E=1e7)가 실용적 상한**으로
    보인다 — 문헌값 실제 정제(E~2GPa, 40000x)는 이 스케일링을 적용하면
    dt가 25μs까지 줄어 스텝 수가 비현실적으로 커질뿐더러, 그 전에
    1e8 근방에서 이미 별개의 수치 버그를 만난다(§grasp_bag_tablet_ipc_test.py
    에서도 실측 E=2GPa가 explicit·dt=5e-3 조합에서 발산한다고 별도 보고됨 —
    같은 결론으로 수렴).

- **[해결] 정제 형상이 접촉 전부터 즉시 우그러지는 현상 — 원인은
  `contact_d_hat`이 캡슐 자신의 극(pole) 근처 정점 간격보다 커서 생긴
  self-contact 오탐(2026-07-15, `FEM/fem_tablet_solo_diag.py`)**:
  위 강성 스윕 영상들(E=1e6/1e7)에서 정제가 "우그러진(찌그러진)" 채로
  낙하하는 것처럼 보인다는 사용자 지적으로 시작된 조사.
  **1단계 — 정점 덤프로 실제 형상 확인**: `fem_tablet_drop_stiff.py`에
  `DUMP_VERTS=1` 옵션을 추가해 137개 정점 좌표를 여러 시점에 저장,
  matplotlib으로 XZ/XY 단면을 그려보니 — **XY(원형 단면)는 시종일관
  완벽하게 유지**되고 **Z축(장축)만 t=0 직후 즉시 설계값 5.0mm →
  4.64mm(−7.2%)로 압축된 뒤 이후 1.5초 내내 소수점 3자리까지 완전히
  고정**됨을 확인. 봉투 접촉은 자유낙하 55ms 이후에나 가능한데 이미
  t<1ms에 압축이 끝나 있어 접촉이 원인일 수 없었다.
  **2단계 — 봉투/선반 없이 정제 단독 낙하로 접촉 가능성 배제**
  (`fem_tablet_solo_diag.py`, Plane을 1m 아래 멀리 둬서 200스텝 내 접촉
  불가능하게 설정): 그래도 **k=0(첫 스텝, t=0.35ms)에 동일한 압축이
  즉시 발생**(bbox z: 5.0000→4.6406mm) — 완전히 고립된 상태에서도
  재현되어 "봉투와 무관한 정제 자체/솔버 문제"로 확정.
  **3단계 — 원인 특정**: `make_capsule_tets_v2`가 만드는 137개 정점의
  최근접 이웃 거리를 `scipy.spatial.cKDTree`로 전수 계산한 결과, **극
  바로 아래 링(z=±2.402mm)의 인접 정점 간격이 0.32mm** — 당시 쓰던
  `contact_d_hat=5e-4(0.5mm)`보다 작았다. IPC의 self-contact(자기충돌
  방지) 배리어가 이 근접한(그러나 실제로는 메시 표면상 정상적으로
  가까운) 정점 쌍을 "충돌"로 오인해 첫 스텝부터 극을 안쪽으로 밀어붙인
  것 — 캡슐이 작을수록(mm 스케일) 극 근처 정점 간격도 비례해서 작아지므로
  **d_hat을 조정하지 않으면 작은 형상일수록 이 오탐에 더 취약해진다**는
  점에서 사용자의 "스케일이 너무 작아서인가" 라는 직관이 정확히 들어맞았다.
  **검증**: solo 진단에서 `contact_d_hat=5e-5(0.05mm, 최소 정점간격
  0.32mm보다 확실히 작게)`로 낮추자 200스텝 내내 bbox가 정확히
  4.0000×5.0000mm(설계값)로 고정 — 압축 완전히 사라짐, 자유낙하 물리량
  (com_z 낙하량)도 이론값과 일치. 봉투 포함 시나리오에도
  `contact_d_hat=1e-4(0.1mm)`로 적용해 재실행하니 자유낙하 구간에서는
  설계 형상을 그대로 유지하다가, **봉투 입구 접촉 시점(t≈450ms)부터
  비로소 x≠y인 진짜 비대칭 동적 변형이 나타나기 시작**(이전엔 접촉과
  무관하게 이미 축대칭으로 고정돼 있어 "가짜 형상"이었던 것과 대조적).
  시뮬레이션 시간을 3초로 늘려 완전히 안착할 때까지 실행 확인
  (`fem_tablet_bag_drop_stiff_v2_E1e+07_20260715_005954.mp4`).
  **교훈**: `contact_d_hat`은 오브젝트 간 최소 간극뿐 아니라 **각
  변형체 메시 자신의 최소 정점 간격(특히 곡률이 큰 극/모서리 부근)보다도
  작아야 한다** — 이전 fem_tablet_drop.py의 `d_hat=5e-4`는 "봉투 입구
  통과의 knife-edge 문제"를 기준으로 정해진 값이라 정제 자체의 self-contact
  안전 마진은 검토된 적이 없었다. 앞으로 캡슐/구 등 곡률 큰 FEM 형상을
  쓸 때는 `make_capsule_tets_v2`류 생성자 출력에 대해 최근접 이웃 거리를
  먼저 계산해 `contact_d_hat`이 그보다 충분히(예: 1/3 이하) 작은지 확인하는
  걸 표준 절차로 삼는다.

---

## 9. Solver / Coupler 조합 실험 기록

각 구성요소(Robotarm/Tablet/Samplebag)를 어떤 표현 방식(Rigid/FEM/PBD 등)으로
넣고 어떤 coupler로 묶었는지의 조합별로 무엇을 시도했고 어떻게 풀었는지(또는
아직 못 풀었는지) 정리한다. 상세 조사 과정은 §5~8에 이미 기록돼 있으므로
여기서는 **조합 단위로 인덱싱**하고 핵심만 요약, 자세한 내용은 원 절을 참고.

> **현재(2026-07) 사실상 IPC 커플러만 쓰고 있다** — PBD는 자기충돌 제약과
> 침투 해석이 충돌해 폭발했고(조합 1), SAP는 rigid collider가 전부 mesh 경유라
> 터널링에 취약해서(조합 4) 실전 조합은 거의 IPC로 수렴했다.

### Robotarm(M0609+RG2) 관련 공통 테크닉

이후 조합들에서 반복 사용되는 로봇팔/그리퍼 구현 기법:

- **Mimic joint (4-bar 폐루프 근사)**: RG2 그리퍼는 실물이 4-bar 폐루프 기구라
  RNE 계산이 트리 구조를 요구하는 시뮬레이터에서 그대로 풀 수 없다(§4).
  MJCF `<equality><joint joint1=... joint2="gripper_joint" polycoef="0 1 0 0 0"/>`
  로 능동 관절(`gripper_joint`) 하나만 구동하고 나머지 5개 관절(truss_arm/
  finger_tip×2, mirror)을 1:1 선형 동기화하는 URDF-mimic 방식을 채택
  (`m0609_rg2_v2.xml`). **단, Genesis 1.1.0은 `<equality><joint>`를 제대로
  안 지킨다** — 네이티브 MuJoCo(`mj_step`)는 정상 동작하지만 Genesis에서
  쓸 때는 이 우회가 필요: 6개 gripper DOF를 매 스텝 전부 동일 값으로
  `set_dofs_position`/`control_dofs_position` 직접 호출(폐루프 풀이를
  코드 레벨에서 흉내). 정합 관절/각속도 액추에이터 조합이 기본 Euler
  적분기에서 qacc 발산을 일으켜 `integrator="implicitfast"`로 전환.
- **Convex decomposition (CoACD)**: `f1_flex_finger`/`f2_flex_finger`의
  실제 손가락 패드 메시는 오목(non-convex)이라 충돌 판정에 그대로 쓰기
  까다롭다 — CoACD로 7개의 볼록 조각(`flex_finger_hull_000~006.stl`)으로
  분해해 각각을 독립 collision geom(`friction="1.5 0.02 0.001"`)으로
  MJCF에 주입(`_prepare_robot_mjcf()`, `grasp_bag_tablet_ipc_test.py` 등).
- **Crusher 쪽 별도 기법**: crank-slider 4-bar도 동일한 이유로 폐루프를
  직접 안 풀고, `link3`–`shaft` 연결을 끊은 뒤 `<equality>`로 재접합(§3-1).
  self-collision이 불필요한 대부분의 바디는 collision-free 처리하고, 관통이
  필요한 `Left_Wall`만 별도로 볼록분해(§3-2).

### 조합 1 — Robotarm(Rigid, mimic+convex decomp) + Samplebag(PBD.Cloth) + LegacyCoupler(rigid_pbd) · **실패 → 폐기**

(`M0609_RG2/grasp_bag_test.py`, §5-2)
- PBD 입자 자기충돌 방지 제약과 손가락 mesh 침투 해석이 충돌 → **핑거가
  봉투에 닿는 순간 즉시 폭발**. §5에서 이미 우려했던 "파지 시 particle
  최소 간격 제약이 깨질 수 있다"는 리스크가 실제로 발생한 것.
- 회피책 없이 **IPC 커플러로 전면 전환**하는 것으로 결론(조합 2로 이동).
  PBD 자체는 폐기하지 않고 파우더 표현 등 다른 용도로는 남겨둘 여지 있음
  (§5의 MPM→Rigid→PBD 3단 결합 구상은 아직 미시도).

### 조합 2 — Robotarm(Rigid, mimic+convex decomp) + Samplebag(FEM.Cloth, 2D) + IPC coupler · **성공**

(`M0609_RG2/grasp_bag_ipc_test.py`, `grasp_box_test.py`, `grasp_bag_tablet_ipc_test.py`, §5-2)
- IPC는 PBD를 못 보므로 봉투 재질을 `FEM.Cloth`로 교체. 실측 STL(두께 0
  핀치 실링선 포함)을 그대로 넣으면 self-intersection sanity check 실패 →
  원인은 위상이 아니라 **패널 간격(1.2mm)이 material thickness(2mm)보다
  얇아서 생긴 자기충돌**(로그 레벨을 올려야 보이는 네이티브 에러) — 검증된
  procedural 5-panel 프록시(간격 6mm)로 교체해 해결.
- 초기 버전은 6DOF mimic(v2) 대신 **단순 2DOF(m0609_rg2.xml) +
  `set_dofs_position` 텔레포트**를 썼다 — IPC의 `two_way_soft_constraint`가
  반력을 자체 처리해 PD 게인 튜닝이 불필요했기 때문. 이후 박스 파지
  검증(`grasp_box_test.py`)에서 `control_dofs_position` 통합 호출 +
  `noslip_iterations=20`/`constraint_timeconst=0.005`(정지 시 접촉 소실
  방지) 조합을 확정하면서 v2 6DOF mimic + convex decomp 그리퍼로 이행.
- 결과: 실링부(~1cm) 순수 마찰 파지(weld 없음), 봉투 Δz +125.8mm.

### 조합 3 — Robotarm(Rigid, M0609 복잡 메시) + Tablet(FEM.Elastic) + IPC coupler · **부분 해결 → 최종적으로 조합 5의 근본 원인으로 수렴**

(`M0609_RG2/grasp_bag_tablet_ipc_test.py`, §8)
- 정제가 tetgen 산출 메시(Sphere/STL)면 M0609 앞에서 거의 얼어붙고, `Box`
  primitive만 정상 낙하하는 패턴을 처음 발견한 조합. 당시엔 "TetGen 산출물
  자체가 원인"으로 결론지었으나, 이후 조합 5·6에서 밝혀진 **self-contact
  d_hat 오탐**이 진짜 원인이었을 가능성이 높음(같은 증상, 더 정밀한 원인).

### 조합 4 — Tablet(FEM.Elastic, 실측 2GPa) + Crusher Plate(Rigid) + SAP coupler · **부분 성공(저속) / 실패(고속) → IPC로 대체**

(`FEM/fem_uniaxial_compression.py`, §6-1, §7-7, §7-9)
- Franka 공식 예제 패턴(`sap_coupling/franka_grasp_fem_sphere.py`) 그대로
  quasi-static 압축(plate 속도 0.01mm/s)에는 성공 — 진짜 Rigid-FEM 접촉으로
  σ-ε, F(t), W(t) 실측.
- **터널링 발견**: SAP coupler는 rigid collider를 primitive로 안 쓰고
  **Box plate조차 trimesh→tet 메쉬로 변환**하며 primitive plane은 명시적
  금지(`GEOM_TYPE.PLANE`→raise). 접촉이 `FEMSurfaceTetLBVH`↔`RigidTetLBVH`
  BVH 이산 접촉이라, plate가 한 스텝에 정제 표면 tet 두께를 넘게 움직이면
  겹침을 놓쳐 관통 — plate 속도를 올리면(비-quasi-static) 재현됨.
- **추가 발견**: plate 속도가 0/미정의면 SAP가 contact impulse를 안 보내다가
  penetration이 깊어지면 한 번에 큰 임펄스로 튕기는 불연속 spike 거동(§7-9).
- 결론: primitive contact이 진짜 필요한 조합(빠른 충돌)엔 IPC가 맞고, SAP는
  quasi-static 압축처럼 느린 케이스에만 신뢰. dt 축소/substeps 증가/plate
  속도 ramp로 완화는 가능하나 근본 해결은 아님.

### 조합 5 — Tablet(3D FEM.Elastic, fan tetrahedralization) + Samplebag(2D FEM.Cloth) + IPC coupler · **해결**

(`utills/primitive_tablet_generator.py`, `FEM/fem_tablet_drop.py`,
`FEM/fem_tablet_drop_stiff.py`, `FEM/fem_tablet_solo_diag.py`, §8)

TetGen을 아예 안 쓰고 표면을 파라메트릭 방정식으로 생성 + 사면체는 순수
기하학적으로 계산하는 방식(§8) 자체가 핵심 아이디어. 이 조합에서 겪은
문제가 가장 복잡해 3단계로 풀렸다:

1. **얼어붙음(1차, v1 fan tet)**: 전역 centroid 하나로 부채꼴 이으면 극(pole)
   근처에 종횡비 나쁜 sliver tet가 다수 생김(반지름 2.5mm인데 극-centroid
   거리 6mm) → M0609/FEM.Cloth 양쪽 모두에서 얼어붙음. `make_capsule_tets_v2`
   (medial-axis 다중 앵커: 반구는 자기 중심점, 원기둥은 축 위 국소 앵커 +
   표준 프리즘→3-사면체 분해)로 sliver를 대폭 줄여(edge-비율 15.0→6.25)
   해소 — Box와 거의 동일한 정상 낙하 회복.
2. **강성 상향 스윕**: 위 해결로 확보한 v2 캡슐 + explicit dt를 파동속도
   스케일링(`dt ∝ 1/√E`)해가며 E를 5e4(안정화용)→1e6(20x)→1e7(200x)까지
   올려도 발산 없이 낙하·안착(`fem_tablet_drop_stiff.py`). E=1e8(2000x)에서는
   "중력을 무시하고 정지"하는 별개의 새 현상 재현 — 강성-질량 수치 불균형
   가설, 원인 미확정.
3. **"우그러짐"의 진짜 근본 원인(최종)**: 위 1·2단계 내내 정제가 접촉 전부터
   미세하게 압축된 채로 보였던 게 사실은 **`contact_d_hat`이 캡슐 극 근처
   정점 간격(0.32mm)보다 컸던 것**(당시 값 5e-4=0.5mm) — IPC self-contact
   배리어가 정상적으로 가까운 인접 정점을 충돌로 오인해 t=0(접촉 불가능한
   자유낙하 중)부터 극을 짓누름. 봉투/선반 없는 정제 단독 낙하로 재현해
   접촉 무관함을 확정하고, `scipy.cKDTree`로 최근접 이웃 거리를 실측해
   d_hat을 그보다 충분히 작게(1e-4~5e-5) 낮추자 완전 해소 — 자유낙하 중
   설계 형상 그대로 유지, 봉투 접촉부터 비로소 진짜 동적 변형 시작.
   **교훈(표준 절차화)**: 곡률 큰 FEM 메시는 `contact_d_hat`을 정할 때
   오브젝트 간 간극뿐 아니라 **메시 자신의 최소 정점 간격**부터 확인할 것.
4. **위 3가지가 사실 하나로 수렴**: "강성을 올릴수록 얼어붙음이 심해진다"
   (앞서 관찰)와 "self-contact 오탐이 근본 원인"(나중 발견)을 합치면, 극의
   가짜 self-contact 고정력이 재질이 뻣뻣할수록 몸체 전체 움직임을 더 강하게
   묶어버리는 것으로 설명됨 — 작은 정제(정점 간격이 더 촘촘)일수록, 강성이
   높을수록 같은 d_hat 버그가 "약간의 압축"에서 "완전한 정지"까지 다양한
   심각도로 나타난다.

### 조합 6 — Tablet(Rigid Body, MJCF capsule geom = SDF) + Samplebag(FEM.Cloth) + IPC coupler · **해결**

(`FEM/rigid_capsule_tablet_bag_ipc_test.py`, `FEM/fem_tablet_drop.py`
`TABLET_MODE=rigid_sdf`, §8)
- 정제를 변형체가 아니라 **강체 SDF**(Genesis에 `Capsule` 모프 클래스는
  없지만 MJCF `<geom type="capsule">`는 `GEOM_TYPE.CAPSULE`, 즉 메시가 아닌
  radius+height 파라미터의 analytic 표현으로 처리됨)로 넣으면 형상 왜곡이
  원천적으로 불가능해진다는 아이디어.
- **1차 시도 실패**: `coup_type="two_way_soft_constraint"`로 접촉 순간 위치가
  수 미터로 발산. `constraint_strength`를 100→0.5로 낮추면 발산은 막히지만
  감쇠 없는 바운스가 계속됨 — 근본 원인 미상으로 잠정 보류.
- **원인 특정**: `coupler.py`의 `_setup_coupling_config`가 `coup_type=None`
  일 때 **`entity.n_joints>0`(관절 있음, freejoint 포함)이면 자동으로
  `two_way_soft_constraint`**를 선택함 — 이건 PD로 계속 구동되는 제어
  대상(로봇 팔 등)을 위한 경로다. 캡슐의 MJCF `<freejoint/>`가 "관절 1개"로
  카운트되어, 아무 명령도 받지 않는 순수 낙하체에 잘못된 경로가 자동
  적용된 것.
- **해결**: `material=gs.materials.Rigid(coup_type="ipc_only", ...)`로
  자동선택을 명시적으로 override(Plane/Shelf가 이미 쓰던, 검증된 one-way
  경로 — "IPC가 중력·동역학 전부 담당"). `constraint_strength`는 기본값
  100 그대로 두고도 발산 없이 낙하→봉투 입구 통과→바닥 안착까지 성공.
- **한계**: 강체라 정제의 압축·파손 거동은 볼 수 없음 — 그런 관찰이
  필요하면 조합 5(FEM+FEM)를 쓴다.

### 조합 7 — Tablet(FEM.Elastic, Box primitive vs 우리 정의 analytic Box) + Samplebag(FEM.Cloth) + IPC coupler · **변인통제 실험(조합 5 진단용)**

(`utills/primitive_tablet_generator.make_box_tets`, §8)
- 조합 5의 sliver 가설을 검증하기 위한 대조군: `gs.morphs.Box`(TetGen 경유)
  vs 우리가 fan tetrahedralization으로 직접 만든 analytic Box(정점 9개/
  tet 12개, TetGen 미사용) — 둘 다 FEM.Cloth 앞에서 거의 완전히 동일한
  정상 자유낙하(106.5/68.6/-81.1mm vs 106.55/68.62/-81.10mm, t=50/100/200ms).
  **결론**: "TetGen 경유 여부"는 무관했고, 우리 수식 정의 방식 자체도
  정상 — 문제는 항상 캡슐의 sliver/self-contact 쪽이었다.

### 조합 8 — Tablet(Rigid+SDF) + Samplebag(FEM.Cloth) + Robotarm(Rigid, mimic+convex decomp) + IPC coupler · **미해결 → Tablet을 FEM으로 우회해 파이프라인은 완성**

(`M0609_RG2_Tablet_Samplebag/tablet_bag_grasp_pipeline.py`, 2026-07-15)

조합 2(로봇+봉투)와 조합 6(정제+봉투)는 각각 따로는 검증됐으니, 셋을 합쳐
"정제 낙하 → 봉투가 받음 → 로봇이 봉투(+정제)를 파지·리프트"하는 최종
워크플로우를 그대로 합쳐서 시도했다.

**증상**: 셋을 한 씬에 합치자 로봇을 전혀 구동하지 않아도(정지 상태로 두기만
해도) 정제 위치가 단 1~2 스텝만에 지수적으로 발산했다(k=1에 2.9m, k=11에
10²³mm 스케일). `constraint_strength_translation/rotation`을 100(로봇 단독
검증값)→30→10 으로 낮춰도 15~30스텝 내 동일하게 발산. **1.0까지 낮추면
발산은 멈추지만, 이번엔 정제가 봉투를 그대로 뚫고 바닥까지 가속 낙하**해
버렸다(접촉 해석 자체가 무력화됨) — 즉 "로봇 파지에 필요한 강한 결합"과
"정제의 정상적인 접촉 해석"을 동시에 만족하는 `constraint_strength` 값을
찾지 못했다.

**원인 조사**: Genesis 공식 예제(`examples/IPC_Solver/*.py`) 4개를 전수
확인한 결과, `ipc_robot_cloth_teleop.py`에 Rigid(Franka, `two_way_soft_
constraint`) + FEM.Cloth + Rigid(`ipc_only`)의 **같은 조합이 존재**하지만,
그 `ipc_only` 엔티티(16개 박스)는 전부 **`fixed=True`(정적 소품)**였다.
그 예제의 커플러 설정(`enable_rigid_rigid_contact=True`,
`newton_semi_implicit_enable=False`, `contact_resistance=1e7`,
`newton_tolerance=1e-1` 등, 우리보다 훨씬 느슨함)을 그대로 우리 씬에
적용해도 발산은 재현됐다 — 즉 "설정 미스매치"가 아니라, **동적(freejoint)
`ipc_only` 강체가 `two_way_soft_constraint` 강체와 같은 IPC 시스템에
공존하는 조합 자체가 검증된 바 없는 조합**으로 판단된다(`ipc_objects_
falling.py`는 동적 `ipc_only` 박스가 있지만 `two_way_soft_constraint`
엔티티가 아예 없는 씬이라 이 조합을 커버하지 않음). 코드 레벨 근본 원인은
미확정(후속 조사 항목).

**우회(채택)**: 정제를 Rigid+SDF 대신 **FEM(조합5, sliver-free 캡슐)**으로
바꿨다 — 그러면 씬의 Rigid 엔티티가 로봇 하나뿐이라 `ipc_only`+
`two_way_soft_constraint` mismatch 자체가 사라진다. `constraint_strength`
를 로봇 단독 검증값(100.0) 그대로 쓸 수 있었고, `contact_d_hat=1e-4`(조합5
self-contact 교훈 반영)로 정제도 낙하 중 형상 왜곡 없이 정상 동작.
**결과: 발산 없이 전체 파이프라인 완주** — 정제 낙하(492.97→426.57mm,
봉투 안 안착) → 그리퍼 파지 → 리프트(finger Δz=+126.1mm, bag grip
Δz=+125.9mm, tablet Δz=+89.6mm, 봉투/정제 동반 상승 둘 다 OK).

**교훈**: `coup_type`을 엔티티별로 다르게 섞을 때(`ipc_only` + `two_way_
soft_constraint` 등), 최소 하나가 **동적(freejoint)** 이면 공식 예제로
검증되지 않은 조합일 수 있다 — 강도 파라미터를 아무리 튜닝해도 "발산 아니면
접촉 무력화"라는 양자택일만 나올 수 있으니, 이런 조합을 새로 시도할 땐
먼저 공식 예제에 정확히 같은 조합(정적/동적 여부까지)이 있는지 확인하고,
없으면 파라미터 튜닝보다 **한쪽을 같은 도메인(FEM 등)으로 통일**하는 우회를
먼저 고려하는 게 시간 대비 효율적이다.

### 조합 9 — Crusher(Rigid) + 알루미늄 플레이트 4개(Rigid, 정적) + Tablet(FEM) + Samplebag(FEM) + Robotarm(Rigid, mimic+convex decomp) + IPC coupler · **해결, 전체 시퀀스(파지→리프트→슬롯 삽입) 성공**

(`Crusher_M0609_RG2_Tablet_Samplebag/full_workflow.py`, 2026-07-15)

조합 8 파이프라인에 Crusher 본체와 알루미늄 플레이트 4개(작업대)를 추가해
"정제 낙하 → 봉투가 받음 → 로봇이 봉투를 파지·리프트 → Crusher 슬롯까지
이동 → 슬롯에 삽입"까지 전체 워크플로우를 완성했다.

**CUDA 크래시 2건 (모두 `coup_type` 미지정이 원인)**:
1. Crusher 추가 시 `cudaErrorInvalidDevice`(scene.build() 내부 advance()에서
   발생) — 자동선택이 `external_articulation`을 골랐는데, 이는 모든 링크가
   충돌 지오메트리를 가져야 하는 조건이라 Crusher의 장식용 링크(충돌 지오메트리
   없음)에서 `Rigid link has no collision geometry` 예외로 이어짐. **해결**:
   `material=gs.materials.Rigid(coup_type="two_way_soft_constraint")`를
   Crusher에 명시(관절이 있는 구동체이므로 로봇과 동일 취급).
2. 알루미늄 플레이트 4개 추가 시 재발 — 원인은 플레이트가
   `gs.materials.Rigid()`로 `coup_type` 미지정(자동선택) 상태였던 것.
   **해결**: 플레이트도 `coup_type="ipc_only"` 명시(Plane/Shelf와 동일
   패턴 — 무관절 정적 소품).
   조합 8 교훈("엔티티별 coup_type을 섞을 때 최소 하나가 동적이면 위험")의
   실전 재확인: 이번엔 반대로 **모든 엔티티에 coup_type을 명시적으로
   지정**하는 것 자체가 근본 해결책이었다(자동선택에 맡기지 않음).

**봉투 형상 고정 — `set_vertex_constraints`의 IPC 커플러 버그 발견**:
로봇을 Crusher 슬롯 근처(거리 0.87m)에 두자 IK 오차가 8~12cm로 컸다.
로봇을 슬롯에서 ~0.65m 거리로 재배치하니 오차가 <0.001m로 줄었다(고정
자세 제약 하에서 IK 수렴은 로봇 베이스로부터의 거리에 매우 민감함).

첫 실행에서 봉투가 아무 지지 없이 중력만으로 버티다 정제가 채 들어가기도
전에 처져버렸고(§5), 이후 그리퍼가 126mm 올라가는 동안 봉투는 제자리에
그대로 남아 파지가 완전히 실패했다. 조사 결과 봉투를 고정하는 함수가
프로젝트 어디에도 없었다 — grasp 자체는 순수 마찰 접촉으로 설계돼 있었지만
(치트 없음), 그 이전에 형상 자체가 무너져 파지 대상이 사라진 것.

Genesis `FEMEntity.set_vertex_constraints()`가 정확히 이 용도(PBD의
`fix_particles_to_link` 대응)지만, 소스 확인 결과 버그가 있었다
(`fem_entity.py` 900행 부근):
```python
if isinstance(self.sim.coupler, IPCCoupler):
    gs.raise_exception("This method is only supported by IPC coupler.")
```
조건이 뒤집혀 있어 "IPC 커플러에서만 지원됨"이라는 메시지와 반대로 **IPC
커플러를 쓸 때 정확히 예외를 던진다** — 우리 씬은 전부 IPC 커플러이므로
이 메서드가 사실상 항상 막혀 있었다(실측 확인:
`bag.set_vertex_constraints(...)` → `GenesisException`). `update_constraint_
targets()`/`remove_vertex_constraints()`는 이 체크가 없어 정상 동작.

**우회**: Genesis 설치본(site-packages)은 건드리지 않고, 원본 로직을 그대로
복제하되 버그인 `isinstance` 체크 한 줄만 제거한 함수로 런타임에
`FEMEntity.set_vertex_constraints`를 몽키패치(`utills/fem_ipc_workarounds.
patch_fem_vertex_constraints()`, `primitive_tablet_generator.py`의
`mesh_to_elements` 패치와 동일한 기법).

고정 정점 범위는 3회 반복 튜닝: 정점 77%(입구 제외 전부)를 고정하니 자유
상태인 입구가 오히려 비현실적으로 늘어남(50스텝 내 -390mm) → 바닥 밴드
(12mm)만 고정하니 150스텝까지는 버티다 이후 붕괴(z-span 88.7→31.8mm) →
**바닥(12mm) + 양 측면(각 8mm), 입구만 완전히 자유** = 정점 303/771(39%)
고정이 격리 테스트에서 설계 치수(90mm z-span)를 200+ 스텝(1초+) 안정
유지함을 확인. `close`(그리퍼 닫기) 직전에 `remove_vertex_constraints()`로
전부 해제, 이후 `grasp`/`lift`는 순수 마찰로 진행.

**결과 (`_full_workflow_run2.log`)**: 고정 적용 후 `prep`/`drop`/`settle` 동안
봉투 COM이 사실상 고정(0.4321→0.4322, 5번째 소수점 드리프트)된 채 정제가
정상적으로 낙하(456.83→431.44mm)했고, 해제 후 `close`→`grasp`→`lift`에서
봉투 COM_z가 0.4315→0.5560(+125.9mm)로 상승해 finger_z 상승분(0.4360→
0.5621, +126.1mm)과 거의 정확히 일치 — **순수 마찰 파지가 실제로 성공**한
것을 수치로 확인(이전 실행에선 finger_z는 동일하게 126mm 올라갔지만
bag_com은 완전히 그대로였음 — 완전한 반전). `above`/`insert` 구간에서는
봉투·정제가 팔의 이동을 따라 흔들리며 이동했고(스윙 있음), 최종적으로
봉투가 Crusher 슬롯 가이드 벽 틈 사이로 내려간 것을 `bagcam` 영상 프레임
(`insert_end`, `end`)으로 시각 확인함 — 그리퍼에 물린 흰색 봉투 메쉬가
슬롯의 검은 가이드 벽 사이에 걸쳐 있는 모습.

영상: `RESULT/full_workflow_20260715_162834_overview.mp4`,
`RESULT/full_workflow_20260715_162834_bagcam.mp4`.

**교훈**: (1) 복잡한 다중 엔티티 IPC 씬에서는 **모든** Rigid 엔티티에
`coup_type`을 명시하는 편이 안전하다(자동선택 규칙이 장식용 충돌-지오메트리
없는 링크나 무관절 소품에서 예상 밖의 타입을 고를 수 있음). (2) Genesis API
문서/타입힌트만 믿지 말고 실제 예외가 발생하면 소스를 직접 읽을 것 —
`set_vertex_constraints`의 `isinstance` 체크는 정확히 반대로 뒤집힌 버그였고
메시지만 봐서는 알아챌 수 없었다. (3) FEM 형상을 grasp 전 안정화할 때는
"입구/파지 대상 부위는 자유, 나머지 골격(바닥+측면)만 고정"하는 최소 고정이
과다 고정(전체 고정)보다 결과가 좋다 — 과다 고정은 해제 안 된 자유 영역에
비현실적 응력 집중을 유발한다.

### 조합 9 후속 — 씬 튜닝 · 슬롯 삽입 위치 재조사 (2026-07-15 2~5차)

(`Crusher_M0609_RG2_Tablet_Samplebag/full_workflow.py`, run3~run7)

조합 9 1차 성공 이후 사용자 시각 검수 피드백을 반영해 5차례 재실행하며
장면 품질·삽입 위치·기구 이해를 다듬었다.

**1) 조명/배경 튜닝**: 기본 조명(ambient 0.1, key light 1개 intensity 5.0)이
너무 어두워 45도 키 라이트(intensity 8.0) + 필 라이트(3.0) + ambient 0.35 로
올렸더니 이번엔 명암 대비가 거의 없이 밋밋(washed-out)해짐 → ambient 0.16,
key 6.0, fill 1.2 로 재조정해 대비를 되살림. 격자무늬 Ground 는
`gs.morphs.Plane(visualization=False)`로 충돌(안전망)은 유지하되 렌더만 꺼서
알루미늄 플레이트만 보이게 함.

**2) `contact_d_hat` 축소 시도 → 성능 폭증 → 원복**: 정제 우그러짐 재발
우려로 `IPC_D_HAT` 1e-4→5e-5 로 낮췄더니 `scene.build()` 내부 warm-start
솔브가 30분+ 로 폭증(직전 1e-4 실행은 빌드+전체스텝+인코딩 합쳐 16분18초).
원인: `contact_d_hat`은 정제 하나의 self-contact 뿐 아니라 **씬 전체(플레이트
4개+Crusher+로봇+봉투+정제)의 모든 접촉쌍**에 적용되는 커플러 전역 설정이라,
민감도를 2배 높이면 이 복잡한 다중 엔티티 씬 전체의 접촉 해석 비용이
크게 늘어난다 — 격리 테스트(정제 단독)에서는 이 비용이 안 보였던 것. 정제
극 근처 최소 정점 간격(0.32mm) 대비 1e-4 의 비율은 0.31 로 이미 문서 기준
"1/3 이하" 안전 마진 안이었으므로 원복(1e-4).
**교훈**: 씬 전역 파라미터를 국소 문제(특정 엔티티의 self-contact) 해결
목적으로 낮출 땐, 그 파라미터가 정말 국소적인지부터 확인할 것 — 아니라면
전체 씬 규모에서 비용을 먼저 가늠해야 한다.

**3) 실링부 색칠 — vertex color 는 무시됨, UV+텍스처만 동작**: Genesis 는
mesh 에 구운 `vertex_colors`(PLY 로 저장해도)를 렌더에 반영하지 않는다(격리
테스트로 확인 — 단색으로만 나옴; `utils/mesh.py`의 `_get_texture`가
`ColorTexture`/`ImageTexture` 두 경우만 처리하고 mesh 자체의 vertex color
경로가 없음). 대안으로 봉투 로컬 좌표(폭 ±32mm, 높이 ±45mm, 이미 원점 중심)에
평면 UV(`u=x/64mm+0.5, v=y/90mm+0.5`)를 구워 OBJ 로 내보내고, 좌우 가장자리
10mm 대역(`|local_x|>22mm`)만 다른 색인 128×128 스트라이프 텍스처를
`surface=gs.surfaces.Default(diffuse_texture=gs.textures.ImageTexture(...))`
로 입혀 해결 — 격리 렌더 테스트로 확인.

**4) 파지 위치를 봉투 최상단(입구)으로 이동**: `TOP_GRIP_MARGIN=8mm` 추가,
`BAG_POS_z = FINGER_MID_z - BAG_HALF_H + TOP_GRIP_MARGIN`(이전엔 봉투
중앙 높이가 FINGER_MID 와 일치) — 그리퍼가 입구에서 8mm 안쪽을 물고, 봉투
대부분이 그 아래로 늘어지는 구조로 변경.

**5) 슬롯 삽입 위치 — 3단계 시행착오**:
   - *5-1 (경험적 보정)*: gap 슬릿 중심(gap_cx,gap_cy)을 목표로 주면 파지된
     봉투가 관성/처짐으로 목표에 못 미쳐(벽 쪽 -42/-28mm 부족) 도착 — 실측
     shortfall 만큼 목표를 벽 쪽으로 미리 밀어 보정(1차 완화, 완전 해결은
     아님).
   - *5-2 (포켓 바닥판 오인)*: "봉투 하단이 벽 쪽에 더 붙어야 한다"는 지적을
     "`L1_Wall1_1`(포켓 바닥 플레이트) 중심까지 가야 한다"로 확대 해석해
     목표를 그쪽으로 옮김. 하지만 이 바닥판은 12mm 폭 gap 슬릿보다 더
     안쪽(-x 방향)에 있어 단순 수직 하강으로는 도달 불가능한 자리였다 —
     실측 로그에서 `insert`/`settle2` 내내 bag_com.x 가 목표로 수렴하지 않고
     **오히려 멀어지는** 패턴으로 이를 확인(벽 구조물에 막힘).
   - *5-3 (근본 수정, docs/Crusher.md 재확인)*: `Crusher.md` §5·§11-5 를 보면
     `Left_Wall`(`L1_Guide1_1_L2_Left_Wall1_1`, Motor2, Rack&Pinion)이 바로
     "샘플백 홀더" — "모터를 계속해서 구동시킴을 통해서 강하게 고정"한다고
     명시돼 있다. 즉 **봉투를 포켓 깊숙이 옮기는 건 로봇의 역할이 아니고,
     로봇은 gap 근처까지만 옮기면 Left_Wall 이 닫히며 실링부를 Wall3 에
     눌러 고정**하는 게 실제 기구 설계다. 목표를 `Crusher_Samplebag.py` 원안
     (`target_x=gap_cx, target_z=wall_top_z`)으로 되돌림 — 파지점이 이제
     봉투 최상단이라 `gripper_z ≈ 입구 높이`가 `wall_top_z` 목표와 자연스럽게
     대응된다.
   - **저비용 사전검증 스크립트**(`slot_ik_check.py`, 신규): above/insert
     목표에서 로봇팔이 Crusher 본체와 충돌하는지를, 무거운 IPC+FEM 풀 씬을
     빌드하지 않고 **Rigid-only(Crusher+Robot 만, coupler 기본값)** 로 빠르게
     검증(빌드 수십 초 vs 풀 파이프라인 4~16분). `entity.get_contacts
     (with_entity=...)` 로 손가락 제외 링크가 Crusher 와 접촉하는지 확인 —
     above/insert 모두 접촉 0건으로 "로봇팔이 슬롯에 같이 들어가는" 문제는
     Crusher 본체와는 무관함을 확인(사용자가 우려했던 지점). 참고로 같은
     검증에서 팔 아래쪽 링크가 **바닥 plane 과는 접촉**함을 발견했는데,
     본 파이프라인은 로봇을 `set_dofs_position`(운동학적 텔레포트)으로
     구동해 이 접촉이 물리적으로 강제되지 않으므로(렌더상 살짝 파고드는
     정도) 봉투/정제 물리에는 영향 없음 — 미해결 코스메틱 이슈로 남겨둠.

**6) `clamp`/`release` phase 신규 추가 — 미해결 이상 발견**: `insert`/
`settle2` 이후 `Left_Wall` 을 `WALL_OFFSET`(+6mm)→`CLAMP_TARGET`(-5mm, 2.0s)
로 램프하는 `clamp` phase 와, 그 뒤 그리퍼를 여는 `release` phase 를
추가(`Crusher_Samplebag.py` 의 `CLAMP_TARGET` 재사용). **증상**: 명령한
목표는 -5mm 인데 `crusher.get_dofs_position()` 실측값이 **-159.42mm** 로
찍힘 — 물리적으로 불가능한 수치. 그런데 `overview` 카메라로는 clamp 진행
중 벽이 시각적으로 거의 안 움직였고, `bagcam` 에는 봉투(실링부 색 포함)가
가이드 블록과 모터 하우징 사이에 눌린 모습만 보인다. **추정 원인**:
Crusher 가 로봇과 동일하게 `coup_type="two_way_soft_constraint"`(rigid
솔버가 계산한 목표를 스프링으로 IPC 쪽 실제 강체에 당기는 방식)로 처리되는데,
벽이 봉투와 접촉해 저항을 받으면 `constraint_strength=100.0` 스프링이 그
반력을 못 이겨 **rigid 솔버 쪽 DOF 값만 목표를 향해 계속 헛돌며 발산**하고,
IPC 가 실제로 시뮬레이션하는 강체 자체는 접촉에 막혀 거의 못 움직이는
것으로 보인다 — 로봇 손가락-봉투 결합에서 이미 확인된 "soft constraint 가
약해 반력을 못 버틴다" 문제와 같은 계열이, 이번엔 Crusher 자체의 벽-봉투
접촉에서 재현된 것. **미해결** — Crusher 전용으로 `constraint_strength`를
올려보거나, clamp 구간만 다른 결합 방식을 쓰는 등의 후속 조사가 필요하다.

영상: `RESULT/full_workflow_20260715_202218_overview.mp4`,
`RESULT/full_workflow_20260715_202218_bagcam.mp4`(run7, clamp/release
포함 — clamp 수치 이상 있는 채로 저장됨).

**교훈**: (1) "위치가 부정확하다"는 피드백을 받으면 목표를 더 밀어넣기 전에
그 방향이 애초에 기구적으로 맞는 요구인지(문서·실측 로그의 수렴 여부)부터
확인할 것 — 5-2 처럼 도달 불가능한 목표를 밀어붙이면 로그상 "수렴 실패"
패턴(목표에서 멀어짐)으로 드러난다. (2) `two_way_soft_constraint` 의
`constraint_strength` 부족 문제는 로봇-봉투 접촉에만 국한된 게 아니라
**두 way-soft-constraint 로 묶인 어떤 rigid 엔티티든 강한 접촉 저항을 받으면
동일하게 재현될 수 있는 일반적인 실패 모드**로 간주해야 한다. (3) 비싼
풀 IPC+FEM 빌드 전에 rigid-only 저비용 씬으로 IK 목표의 충돌 여부만 먼저
검증하는 방식(`slot_ik_check.py`)이 반복 튜닝 비용을 크게 줄여준다.

### 조합 9 후속 2 — IK 링크 오프셋 버그, 봉투 축 뒤바뀜 버그, 인터랙티브 프로브 (2026-07-16)

(`Crusher_M0609_RG2_Tablet_Samplebag/full_workflow.py`, `interactive_probe.py` 신규)

**버그 A — IK 타깃 링크가 손가락이 아니라 손목 브라켓(`gripper_body`)이었다**:
above/insert IK 를 지금까지 `gripper_body` 링크에 대해 풀고 있었는데, FK
실측 결과 이 링크는 실제 손가락(봉투가 매달린 지점, `f1_flex_finger`)과
**world z 로 140mm, x 로 34mm** 나 어긋나 있었다(RG2 내부 링크(moment_arm/
truss_arm)를 거쳐 손가락이 그만큼 아래에 붙는 구조). `insert_z=wall_top_z`
로 `gripper_body` 를 명령하면 실제 손가락은 140mm 아래(포켓 바닥 근처, 심지어
z<0)까지 내려갔다 — 이전 라운드들에서 "목표에 도달 못 함/벽에 막힘"으로
보였던 현상 상당수가 사실 이 링크 오프셋 때문이었다. **해결**: IK 타깃
링크를 `left_link`(`f1_flex_finger`)로 교체 — 격리 검증 결과 오차 0.19mm,
Crusher 접촉 0건.

**버그 B — `BAG_EULER` 축이 뒤바뀌어 있어 봉투의 넓은 면이 좁은 gap 과
부딪히고 있었다**: `BAG_EULER=(90,0,0)` 에서 봉투의 world 좌표계 크기는
X=64mm(폭+실링), Y=6mm(두께), Z=90mm(높이) 였는데, 슬롯 gap 은 X=12mm(좁음),
Y=65mm(여유) — **봉투의 넓은 면(64mm)이 좁은 12mm gap 과, 얇은 면(6mm)이
여유로운 65mm 쪽과 부딪히는 축이 뒤바뀐 상태**였다(trimesh 로 직접 회전행렬
적용해 검증). 원래 참고했던 `Crusher_Samplebag.py` 는
`BAG_EULER=(90,0,**90**)` 을 썼는데(마지막 Z축 90도가 우리 코드에서 누락돼
있었음) 이걸 추가하면 X=6mm(두께, gap 12mm 대비 여유 3mm씩), Y=64mm(폭, gap
65mm 대비 여유 0.5mm씩 — 타이트하지만 통과 가능)로 정확히 뒤바뀐다. 높이
(local Y→world Z)는 이 변경과 무관하게 그대로 유지된다.
**연쇄 수정**: 그리퍼 닫힘축도 봉투 두께축을 따라가야 하므로 손목(joint 6)
트위스트(+90°, "봉투 두께=world Y 시절"에만 필요했던 우회)를 제거(0°) —
FK 실측으로 wrist=0 일 때 핑거가 world X축으로, wrist=+90°일 때 Y축으로
벌어짐을 확인. `FINGER_MID`(그리퍼 중심 기준점), `SEAL_LOCAL_X` 적용 축
(로컬 폭축이 이제 world Y 로 매핑), 봉투 형상 고정용 `bag_side_mask`(이제
`by` 기준)까지 전부 재측정/수정.

**insert 목표 재확정**: 저비용 rigid-only 스윕(`gap 근처, "벽 중앙+margin"`
z 목표에서 margin 을 100mm→10mm 단위로 낮춰가며 손가락-Crusher 접촉 검사)으로
**margin=52mm(wall_top_z+16mm) 가 접촉 0건인 가장 타이트한 값**임을 확인
(margin=45mm 부터 접촉 발생 — 핑거 폭이 12mm gap 보다 넓어 핑거 자체는 gap
을 통과할 수 없고, 봉투만 통과해야 함).

**인터랙티브 프로브 도구(`interactive_probe.py`, 신규)**: "위치를 계속
추측→실행→영상확인 하는 루프가 너무 느리다"는 피드백으로, 로봇 없이 봉투
치수(6×64×90mm)의 rigid 프로브 박스를 라이브 뷰어에서 마우스로 직접 드래그해
슬롯에 넣어볼 수 있는 도구를 만들었다. Genesis 뷰어의
`MouseInteractionPlugin`(`gs.vis.viewer_plugins`)을 사용.
- **1차 시도(GPU 백엔드 + `use_force=True`(스프링힘) + Crusher 관절을 매
  스텝 PD 로 계속 붙잡음)**: 사용자가 실수로 Crusher 의 크랭크/벽 링크를
  잡으면 스프링힘과 PD 힘이 충돌해 `Invalid constraint forces causing
  'nan'` 발산. 픽업 자체는 되고 있었는데(디버그 로그로 `[pick] OK` 확인)
  이 충돌 때문에 몇 초 안에 항상 죽었다.
  print 출력이 안 보이는 것도 원인 중 하나였다 — stdout 을 파일로
  리다이렉트하면 파이썬이 완전 버퍼링돼서 프로세스가 끝나야 로그가
  한꺼번에 flush 됨(`python -u` 로 해결).
- **해결(공식 예제 `genesis-world/examples/viewer_plugin/mouse_interaction.py`
  그대로 참고)**: CPU 백엔드 + `use_force=False`(스프링 대신 위치를 직접
  set — 발산 자체가 불가능) + Crusher 관절은 루프 진입 전 딱 한 번만
  세팅(이후 매 스텝 PD 로 안 붙잡음, 드래그와 충돌할 대상이 없어짐). 이
  패턴으로 바꾸자 크래시 없이 정상적으로 드래그 가능함을 확인.
- **결과**: 사용자가 직접 프로브를 슬롯에 넣어보고 "슬롯에 삽입하는 문제는
  여유가 있는 것으로 보인다"고 확인 — 버그 A/B 를 고치고 나니 애초에
  걱정했던 "12mm/64mm 타이트 핏" 문제가 실제로는 크게 문제 되지 않음이
  인터랙티브 테스트로 검증됨.

**교훈**: (1) IK 타깃 링크를 고를 때 "엔드이펙터에 가까워 보이는 링크"가
아니라 **실제 작업점(여기선 손가락)과의 FK 오프셋을 먼저 실측**할 것 — 140mm
차이는 육안으로도 눈치채기 쉬웠어야 했는데, 여러 라운드 동안 "위치가 조금
안 맞는다" 정도로만 보여서 놓쳤다. (2) 좌표축 매핑(euler 회전)을 다른
스크립트에서 그대로 가져올 땐 **모든 축의 각도를 다 옮겨왔는지** 확인할 것
— 하나(마지막 Z축 90°)를 빠뜨린 게 몇 라운드에 걸친 "위치가 안 맞는다"
디버깅의 근본 원인이었다. (3) 반복 위치 튜닝이 막히면, 무거운 물리 파이프라인
전체를 반복 실행하기보다 **가벼운 인터랙티브 도구로 사람이 직접 확인**하는
쪽이 훨씬 빠르게 답을 준다 — Genesis 의 `MouseInteractionPlugin` 이 정확히
이 용도로 이미 만들어져 있었다.

---

### 조합 9 후속 3 — Q_GRASP/Q_LIFT 오리엔테이션 기울어짐 (2026-07-24)

(`Crusher_M0609_RG2_Tablet_Samplebag/full_workflow.py`)

`Q_GRASP`/`Q_LIFT`는 IK로 푼 값이 아니라 테스트하며 손으로 고른 조인트각
하드코딩 상수다. FK로 실측하니 손가락 진행축이 완전 수직에서 약 13.8° 기울어져
있었고(파지 시 봉투 비틀림의 유력 원인), 같은 위치에서 quat을 수직으로 강제한
IK는 오차 0.002mm로 수렴하고 조인트 여유도 충분했다 — 로봇 링크 근접에 의한
기구학적 한계가 아니라, 튜닝 당시 엔드이펙터 오리엔테이션을 제약 조건으로
넣지 않아서 생긴 어긋남이다.

### 조합 9 후속 4 — 석션V1 조(jaw) 자기교차, IPC build crash **[미해결, 작업 중]** (2026-07-29)

(`assets/robots/석션V1_description/석션V1.xml`, `full_workflow.py`,
`Fixture_only/fixture_recovery2_stack_sim.py`)

**작업 배경**: 회수장치2+고정장치 위치를 원상 복구(Jig-회수장치2 근접은
설계 의도, +25mm 인위적 Z-갭이 오히려 버그였음을 확인)한 뒤, 석션V1을
`full_workflow.py`에 배치 — 회수장치2의 `F_LeftLink_1`/`F_RightLink_1`
중점에 석션V1의 두 `Suction_Cup_M5_0.8mm` 링크 중점이 오도록 정렬(회수장치2가
봉투를 고정하고 석션V1 석션컵이 양옆으로 당기는 구조). 정렬 후 석션V1
베이스와 고정장치 베이스 간 실제 겹침(link-level AABB)이 발견되어 X를
+0.25m 시프트해 해소했다.

**증상**: 이 겹침을 전부 없앤 뒤에도 고정장치+석션V1, 회수장치2+석션V1,
셋 다 포함 씬 모두 동일하게 `scene.build()` 단계에서
`AttributeError: 'NoneType' object has no attribute 'body_count'`로 크래시
(직전에 IPC가 "Intersection detected" 로그를 찍음).

**진단**: "그동안 잘 됐었는데 왜 지금 죽나?"는 질문에서 출발 — 크로스-엔티티
겹침이 원인이라는 가설로 T1-Jig 케이스처럼 접근했으나 재현 안 됨. 최소
재현 조합(고정장치+석션V1 단 둘만)으로 좁힌 뒤, `entity.links` 순서를 직접
출력해 크래시 로그의 `Object[rigid_link_4_0(2)]` / `Object[rigid_link_5_0(3)]`
인덱스를 링크 이름에 정확히 매핑했다(이전 시도에서 인덱스 산수를 암산으로
하다가 다른 2-엔티티 조합에서 같은 인덱스 4/5가 나와 오판했던 적이 있어,
이번엔 실제 출력으로 확정): 인덱스 4/5 = **석션V1 자신의**
`L_E-SMLG9H-100-ES10_2_1` / `R_E-SMLG9H-100-ES10_2_1` (좌우 조 링크).
즉 크로스-엔티티 문제가 아니라 **석션V1 조 자체의 자기교차**였다.

**왜 "전에는 문제없었나"**: 두 조 링크는 기본 배치(`pos` y=+0.00345 /
-0.00345, 간격 약 6.9mm)에서 이미 항상 살짝 겹쳐 있었던 것으로 보인다.
IPC의 build-time 자기교차 유효성 검사(`coupler.build()` →
`_init_accessors()`)는 **공간적 근접성에 의존하는 것으로 추정**된다 —
석션V1이 씬에 혼자/다른 바디들과 멀리 떨어져 있을 땐 이 자기교차를
용인하다가, 다른 리지드 바디(고정장치/회수장치2)와 가까이 배치되자 같은
자기교차를 엄격하게 걸러낸 것으로 보인다(broad-phase 공간 분할/pruning
휴리스틱 추정, Genesis 내부 확인은 못 함).

**시도했다가 안 통한 것**: `contype`/`conaffinity` 비트마스크로 조끼리
충돌 제외 → 효과 없음(IPC 자기교차 검사는 MuJoCo 스타일 필터링을 무시하는
것으로 보임). MJCF `<contact><exclude body1=".." body2=".."/>` 직접 추가 →
ElementTree로 넣으니 무관한 파서 버그(`KeyError: 'vmesh'`) 유발, 이 경로는
포기.

**작동한 것(확인됨, 아직 실파일엔 미적용)**: 두 조 링크의 y-오프셋을
바깥쪽으로 대칭 확장(`extra_offset`, 원래 `±0.00345`에 가산) — 조 간격을
넓혀 자기교차 자체를 없애면 build 성공. 이진 탐색 결과:
- 편측 20~29mm 추가 오프셋(총 간격 ~46.9~64.9mm) → 전부 FAIL(여전히 crash)
- 편측 30mm 추가 오프셋(총 간격 ~66.9mm) → OK(build 성공)
- 29~30mm 사이 정밀 임계값은 미확정(세밀 이진 탐색이 도구 오류로 중단됨,
  다음 세션에서 이어서 진행 예정)

**현재 상태**: `석션V1.xml`의 조 링크 `pos`는 아직 원래 값
(`0.00345`/`-0.00345`) 그대로다 — 조 간격을 넓히는 실제 수정은 다음
작업에서 진행. 이 문제가 풀리기 전까지 고정장치+회수장치2+석션V1을 모두
포함하는 `full_workflow.py`의 최종 영상 재생성은 보류 상태.

### 조합 10 — 파우더 담기: MPM(과립) + {FEM/PBD}(봉투) + Legacy 커플러 **부분 해결**
(2026-07-28~30)

(`Powder_flip_test/powder_containment_test.py`)

**목표**: 회수장치로 파우더를 봉투에 담는 실험(§8 목표)의 사전 단계로, 로봇팔/
회수장치는 배제하고 "MPM.Sand 파우더가 봉투 내부 공간에 실제로 들어가는가"만
격리 검증. `BAG_BACKEND`(pbd/fem) × `TEST_MODE`(pour/rigid_probe/legacy_sanity)
env var로 조합 전환.

**시도 1 — FEM.Cloth(봉투) + MPM.Sand, `fem_mpm` 커플러 → build crash**
(`_fem_run1.log`, BAG_BACKEND=fem). `scene.build()` 중
`QuadrantsSyntaxError: ... Unsupported node "Raise"`
(`FEM/base.py:_update_stress_noop`에서 발생). 원인은 커플러 옵션이 아니라
**재질 자체의 설계 제약**이었다 — `genesis/engine/materials/FEM/cloth.py`의
`Cloth` 클래스 docstring에 "Only works with IPCCoupler enabled"라고 명시돼
있고, `update_stress`를 오버라이드하지 않는다. Legacy 커플러는 명시적
substep(`fem_solver.compute_vel` → `_mats_update_stress[mat_idx]` dispatch)를
타는데 Cloth는 이 경로용 함수가 없어 base의 noop(raise)이 그대로 호출된다 —
Cloth는 애초에 IPC 전용 설계라 Legacy와는 재질 수준에서 호환 불가.
(Genesis 공식 GitHub `examples/coupling/`에도 fem_mpm 조합 예제는 없음 —
cloth_on_rigid / cloth_attached_to_rigid / fem_cube_linked_with_arm /
sand_wheel / flush_cubes / cut_dragon / water_wheel / sph_mpm / sph_rigid /
grasp_soft_cube 전부 rigid↔fem 또는 rigid↔mpm 조합뿐.)

**시도 2 — FEM.Elastic 평판 + MPM.Sand, `fem_mpm` 커플러(TEST_MODE=legacy_sanity)
→ build 성공, 그러나 커플링 완전 무반응**. Cloth 대신 TetGen이 안전하게
다루는 두께 있는 Box(FEM.Elastic)를 얹어 `fem_mpm` 코드 경로 자체가 동작하는지
격리 검증. `scene.build()`는 성공했지만, 파우더 94.5~94.6%가 평판을 완전히
무시하고 자유낙하 — 낙하한 입자의 `min_z`가 정확히
`MPM_LOWER.z + 3*dx = -0.03 + 3*(1/128) ≈ -0.0066`(MPM 도메인의 3*dx
세이프티 패딩을 뺀 유효 바닥)로, 평판 두께를 6mm→30mm(5배)로 늘려도 **토씨 하나
안 틀리고 동일** — "판이 얇아서 새는" 게 아니라 **커플링 자체가 전혀 발동하지
않고 있음**을 의미. 유력한 원인: `gs.morphs.Box`를 TetGen 기본 설정으로
사면체화하면 극도로 거친 메시(정점 9개, tet 12개 — 사실상 박스 모서리
8개뿐)가 나오는데, `fem_mpm` 커플링은 FEM 표면 정점 단위로 주변 MPM 그리드를
보정하는 방식이라(§조합9후속4 인접 섹션 아님, `legacy_coupler.py` 581~635줄)
평판 중앙처럼 정점이 없는 넓은 영역은 전혀 보정되지 않는 것으로 추정 —
확정 검증은 보류.

**시도 3 — PBD.Cloth(실제 봉투 메시) + MPM.Sand, `mpm_pbd` 커플러(TEST_MODE=pour,
기본 모드) → 부분 작동, 경계선상 누출**. `_pbd_run4_openmouth.log`: 누출
141/8523(1.7%) → CONTAINED. `_pbd_run5_taper.log`: 544/8477(6.4%) → LEAK.
재현 실행(2026-07-30): 407/8534(4.8%) → CONTAINED(임계값 5% 바로 아래). 세 번
모두 실제로 새는 입자는 시도 2와 동일하게 `min_z≈-0.0066`(도메인 유효
바닥)까지 정확히 떨어짐.

**원인 분석(사용자 관찰 — "컨택은 발생하는 것 같은데 내부로 못 들어가고 상단에
쌓인다" — 코드 확인으로 확정, 2026-07-30)**: `legacy_coupler.py` 452~498줄의
`mpm_pbd` 커플링은 **표면/법선 개념이 전혀 없는 순수 근접-기반 속도평균
스킴**이다 — MPM 그리드 노드가 PBD 입자(=봉투 정점) 중 `|Δpos|_inf <
mpm_solver.dx*0.5` 안에 있는 것들을 찾아 그 속도의 평균으로 강제 스냅하고,
반작용 momentum을 그 정점들에 되돌려준다. 안/밖 구분이나 표면 방향 판정이
전혀 없다(`fem_mpm`은 최소한 signed-distance+normal 기반이라 이 문제가 덜함,
단 시도2처럼 메시가 너무 거칠면 그마저도 무용지물). 수치 확인:
봉투 STL(`Samplebag_seal_pouch3.stl`, 4512 vertices, 64×90×6mm)의 실측 정점
간격은 약 1.7~2mm인데, 이 커플링의 포착 반경은 `dx*0.5 ≈ 3.9mm`(그리드
dx=7.8mm 기준) — 정점 간격이 포착 반경보다 훨씬 촘촘해 입구 테두리를 따라
포착 영역이 전부 겹쳐서, **실제로는 뚜껑 없는 열린 튜브 구멍인데도 입구
평면 전체가 방향 무관 "속도-감쇠 커튼"으로 작동**한다. 낟알이 입구를
향해 내려가도 이 커튼 근처에서 속도가 정점 속도(≈0)로 스냅되어 감속·정지하고,
뒤따르는 낟알이 이미 멈춘 낟알 위에 일반 MPM 입자-입자 역학으로 계속
쌓인다(관찰된 "상단에 쌓임"과 정확히 일치). 소수(1~6%)가 새는 건 더미가
쌓이며 정점 배치가 국소적으로 밀리거나 포착망의 우연한 틈으로 빠지는
경우로 추정.

**§조합5/6/9(FEM 정제+FEM 봉투+IPC)가 성공했던 이유와의 결정적 차이**: 그
조합은 IPC의 CCD(연속충돌감지) 기반이라 실제 메시 표면에 대해 진짜
geometric 침투 판정을 하고, 무엇보다 정제가 **하나의 일관된 물체를 IK로
미리 계산한 경로를 따라 입구를 정확히 겨냥해** 내려보낸 것이었다 — "다수의
자유낙하 입자가 좁은 틈을 확률적으로 찾아 들어가야 하는" 지금 상황과
근본적으로 다른 문제다. `mpm_pbd`는 방향 정보가 없는 구조적 한계상 다수
입자 스트림 담기 용도로는 부적합.

**결론**: FEM.Cloth+MPM(재질 자체 비호환) / FEM.Elastic+MPM(무반응) 둘 다
탈락. `PBD.Cloth+MPM`만 실질적으로 작동하나 누출률이 임계값(5%) 바로 근처를
오르내려(1.7%~6.4%) 안정적이라 보기 어렵다. 커플러 옵션은 필요한 것 하나만
켜고 나머지 전부 False로 끄는 최적화(계산비용 절감) 적용 완료. 다음 단계
후보: 마우스 테이퍼 형상 조정으로 누출을 임계값 아래로 확실히 낮추거나,
이 파우더 담기 용도는 이미 검증된 IPC 커플러(정제처럼 "담긴 알갱이 여러 개
= 작은 FEM.Elastic 엔티티"로 표현, `main_ipc()` 함수 참고)로 가는 방안.

### 조합 11 — pyuipc 네이티브 Particle 커플러 자작 + IPC 바닥면 위치 버그 발견 (2026-07-31)

(`Powder_flip_test/ipc_grain_coupler.py`, `Powder_flip_test/sand_wheel_repro.py`)

**배경**: 조합10에서 Legacy 계열(`fem_mpm`/`mpm_pbd`)이 전부 봉투 담기에 부적합함을
확인한 뒤, "Genesis의 IPC 커플러는 FEM-Rigid만 알고 다른 재질 커플링은 아예
없는데, 그 밑단의 pyuipc(libuipc) 자체는 더 다양한 재질을 지원하지 않느냐"는
질문에서 출발. 실제로 `uipc.constitution.Particle`("point-mass simulation")
+ `uipc.geometry.pointcloud()`(dim()==0 SimplicialComplex)가 존재하고,
`Particle.apply_to(sc, mass_density, thickness)`로 접촉용 "두께"(유효 반경)를
가진 점질량을 만들 수 있으며, libuipc의 GUI/SceneVisitor 코드도 pointcloud를
tetmesh(FEM 체적)/trimesh(FEM.Cloth)/linemesh(rod)와 나란히 1급 지오메트리로
다룬다 — 즉 FEM.Cloth와 **같은 IPC Scene 안에서 동일한 CCD 기반 접촉**으로
알갱이를 표현할 길이 있었다.

**구현**: Genesis 설치 패키지를 직접 고치지 않고, `genesis.engine.couplers.
ipc_coupler.coupler.IPCCoupler`를 상속하는 `GrainIPCCoupler`를 별도 스크립트
(`ipc_grain_coupler.py`)로 작성 — `_add_fem_entities_to_ipc`/`_register_
contact_pairs`/`_retrieve_fem_states` 패턴을 그대로 따라 `_add_grain_
entities_to_ipc`(pointcloud+Particle 등록)/오버라이드한 `_register_contact_
pairs`(알갱이-cloth/rigid/ground/알갱이끼리 접촉쌍 추가)/`_retrieve_grain_
states`(dim()==0 지오메트리 상태 회수)를 추가했다. Genesis는 `coupler_options`
타입만 보고 내부적으로 `IPCCoupler`를 직접 생성하므로(`simulator.py`), `gs.
Scene()` 생성 직후 `scene.build()` 전에 `scene._sim._coupler`를 이 서브클래스
인스턴스로 바꿔치기하는 방식으로 끼워 넣었다.

**시행착오 2건(둘 다 코드 레벨에서 원인 확정)**:
1. 첫 sanity 테스트(강체 바닥+알갱이)가 crash 없이 통과했지만 알갱이가
   바닥을 완전히 무시하고 자유낙하 — 원인은 다른 모든 지오메트리(FEM 314줄,
   Rigid 462줄)와 달리 pointcloud에 `uipc.geometry.label_surface(mesh)`를
   빠뜨렸기 때문(직접 재현: `label_surface` 호출 전엔 `is_surf` 속성이
   없어 접촉 판정 대상에서 아예 빠짐, 호출 후엔 정상). 추가 후 알갱이가
   정확히 반지름 위치에서 멈춤 확인.
2. 영상에 알갱이가 하나도 안 보임 — 알갱이는 Genesis 엔티티가 아니라
   `scene.draw_debug_spheres()`로 그린 마커뿐이라, `genesis/vis/
   rasterizer.py:76`의 `skip_markers = not camera.debug`에 걸려 기본
   카메라 렌더에서 통째로 스킵됐다. `scene.add_camera(..., debug=True)`로
   해결(직접 최소 재현으로 확인).

**성공 신호**: 실제 봉투(FEM.Cloth)+알갱이(Particle) 조합에서 낙하한 알갱이
대부분이 봉투 내부 바닥 쪽에 정상적으로 쌓였다(영상 프레임으로 시각 확인) —
mpm_pbd처럼 입구 위에 쌓이는 현상과 다름. 다만 누출률이 3.3~11.7% 사이에서
런마다 흔들려(GPU 부동소수점 비결정성 추정) 조합10과 마찬가지로 임계값
근처를 오갔다.

**별개의 근본 원인 추가 발견(사용자 관찰 "봉투가 바닥까지 늘어나며 찢어지는
것 같다"에서 출발)**: `BAG_CONSTRAINT_MODE` 변인통제(바닥/옆면/입구 고정을
"기존대로"/"입구 벌림 생략하고 원위치만 고정"/"아예 제약 없음" 세 가지로
전환 가능하게 계측 추가)로 확인한 결과, **제약(vertex constraint)이 원인이
아니었다** — 제약을 하나도 안 걸어도 봉투 전체가 똑같이 붕괴했다. 대신
직접 속성 조회로 확인한 진짜 원인: `genesis/engine/couplers/ipc_coupler/
coupler.py`의 `_add_rigid_geoms_to_ipc()`가 바닥면(Plane) 높이를
`height = np.dot(geom.init_pos, normal)`로 계산하는데, `geom.init_pos`는
링크-로컬 좌표라 항상 `[0,0,0]`이다(링크의 실제 월드 위치 `link.pos`는 이
계산에 안 들어감 — 다른 일반 메시 지오메트리는 `trans_view[0] = link_T`로
월드 변환을 따로 적용하는데 Plane 전용 분기만 이 단계가 빠짐). 결과적으로
**`gs.morphs.Plane(pos=...)`에 뭘 넣든 IPC 안에서는 항상 world z=0에 바닥이
생긴다** — 봉투(바닥이 로컬로 약 z=0.065)가 진짜 바닥(z=0)까지 6.5cm를
허공에서 그냥 떨어져 늘어진 뒤에야 멈춘 것이었다. 이건 mpm_pbd/fem_mpm/
Particle 등 커플링 방식과 완전히 무관하게 조합10·11 실험 전체에 공통으로
영향을 준 원인이었다.

**Genesis 버전 업그레이드로 재확인(2026-07-31)**: 사용자가 "이 버그가 Genesis
1.2.3에서 이미 발견됐다"고 언급해 `genesis-world` 1.1.0 → 1.3.1(quadrants
0.8.0 → 1.2.0 동반)로 업그레이드했으나, **`coupler.py:424`의 해당 줄은
1.3.1에서도 완전히 동일**하고 재현 실험 결과도 소수점 4자리까지 이전과
일치 — 이 특정 버그는 아직 안 고쳐진 것으로 확인. 업그레이드 과정에서
`Camera.start_recording`/`stop_recording` API가 바뀐 것도 확인(파일명/fps가
`start_recording`으로 이동, `stop_recording()`은 인자 없음) — 스크립트
수정 완료.

> **[추가 발견 2026-08-03] 이 업그레이드가 `full_workflow.py` FEM 경로를
> 깨뜨려 놨었다 (§13-6 rigid 모드 작업 중 회귀 검증에서 발견).** 두 군데:
> (1) 위 녹화 API 변경이 `full_workflow.py`에는 반영이 안 돼 있어
> `stop_recording(save_to_filename=...)` 에서 `TypeError` — **수정 완료**.
> (2) `utills/primitive_tablet_generator.py`의 `add_analytic_fem_entity`
> (TetGen 우회용 `mesh_to_elements` 몽키패치)가 **0바이트 더미 STL**을
> 만들어 두고 `gs.morphs.Mesh(file=...)`의 파일 존재 검사만 통과시키는
> 구조인데, Genesis 1.3.1의 `FEMEntity.sample()`이 새로 추가한
> `gs.Mesh.from_morph_surface(morph, surface)`(**시각 geom**을 morph 파일에서
> 직접 로드)가 그 빈 파일을 읽어 빈 리스트를 돌려주고
> `merge_submeshes` 가 `ValueError: need at least one array to concatenate`
> 로 죽는다. 1.1.0에서는 sample()이 패치된 `mesh_to_elements` 경로만 탔기
> 때문에 빈 더미로도 통과했었다. **마지막 성공 실행(2026-07-29, b2ba7cb)
> 이후 업그레이드(07-31)가 있었고 그 사이 FEM 모드를 아무도 안 돌려서
> 지금까지 안 보였던 것.**
>
> **[정정] "더미 STL만 채우면 된다"는 진단은 불완전했다.** 실제로 실물
> 캡슐 표면 메시(watertight, 264면)를 그 자리에 써 넣고 재실행하니 한 줄
> 더 가서 **다른 지점**에서 죽었다 — `fem_entity.py:531`:
> ```
> verts, elems = eu.mesh_to_elements(surface_trimesh, tet_cfg=self.tet_cfg)
>   → primitive_tablet_generator.py:325  _orig(file, pos=pos, scale=scale, ...)
> TypeError: mesh_to_elements() got an unexpected keyword argument 'pos'
> ```
> **`mesh_to_elements` 의 시그니처가 바뀌었다**: 1.1.0 `(file, pos, scale,
> tet_cfg)` → 1.3.1 **`(mesh, tet_cfg)`**. 파일 경로가 아니라 trimesh 객체를
> 받는다. 그런데 몽키패치는 `if file in _ANALYTIC_CACHE` 로 **경로 문자열을
> 캐시 키**로 쓰므로 이제 캐시가 절대 안 맞고, 폴백 호출도 없어진 인자를
> 넘겨 죽는다. 즉 **TetGen 우회 메커니즘 자체를 1.3.1 시그니처에 맞춰 다시
> 써야 한다**(캐시 키를 morph 파일 경로가 아닌 다른 것으로 잡거나, 우회
> 지점을 `FEMEntity` 쪽으로 옮기는 등). 한 줄 수정이 아니다.
> 이 유틸은 `add_analytic_fem_entity` 를 쓰는 13개 스크립트가 공유한다
> (`FEM/fem_tablet_*.py` · `Legacy_vs_IPC/pipeline_ipc.py` ·
> `Recovery2_only/recovery2_tablet_drop.py` · `Powder_flip_test/` ·
> `scene_setup.py` · `slot_fit_check.py` 등).
>
> **단, 이건 정제(FEM.Elastic) 한정 문제다.** 봉투(`FEM.Cloth`)는 이 유틸을
> 안 쓰고 일반 `gs.morphs.Mesh` 경로라 무관하다 — 봉투+IPC 자체의 건전성은
> `SKIP_TABLET=1` 로 분리 검증했다(§13-8).
>
> **→ 해결 (2026-08-03), §13-9 참고.**

**Rigid-MPM 베이스라인 재확인**: Genesis 공식 예제 `examples/coupling/
sand_wheel.py`를 headless/GPU 환경으로 이식해 재현(`sand_wheel_repro.py`) —
모래가 각 바퀴 십자 날개에 정확히 부딪혀 튕기며 흘러내림을 영상으로 확인,
crash/관통 없음. `rigid_mpm` 커플링 자체는 안정적이라는 근거 확보 — 문제는
"양쪽 다 변형체/입자"인 조합(`mpm_pbd`, `fem_mpm`)에 국한됨을 뒷받침.

**결론 및 다음 단계**: (1) Particle 기반 접근은 방향성이 맞다(FEM.Cloth와
같은 CCD 경로를 타므로 mpm_pbd의 근본적 한계가 없음) — 다만 바닥면 버그
때문에 이번 실험만으로는 완전한 결론을 못 냄. (2) 바닥면 버그는 Genesis에
직접 보고 예정(GitHub enhancement 문의 초안 작성 완료 — Legacy 커플러의
재질 조합 확장 계획 문의에 포함). (3) 바닥면 버그를 피하려면 봉투를 실제
바닥(항상 world z=0) 바로 위에 오도록 배치하거나, 버그가 고쳐진 이후 버전을
기다려야 함.

### 조합 12 — 접촉/커플링 pair 제어 수단과 MPM 입자 크기의 실질 한계 · **코드 레벨 조사(실행 검증 없음)** (2026-08-11)

**성격 먼저**: 이건 새로 돌린 실험이 아니라 **Genesis 1.3.1 설치본 소스를 직접
읽어 확인한 조사 기록**이다. 아래 표의 비용 수치는 코드의 공식에서 유도한
값이지 실측이 아니다(그렇게 표시해 둠). 조합 10·11 을 재시도하거나 새 조합을
설계하기 전에 "무엇이 되고 무엇이 안 되는가"를 먼저 못박아 두려고 남긴다.
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

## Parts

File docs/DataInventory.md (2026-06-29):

# Data Inventory — Crusher 실험 · 트윈 · 한계 데이터 정리

Crusher 디지털 트윈에서 **무엇을 실험으로 얻고, 무엇을 시뮬(FEM)으로 얻고,
무엇은 못 얻는가**를 한눈에 정리한 인벤토리. 이론·전략 배경은
[`DigitalTwin.md`](DigitalTwin.md) §7, FEM 구현 현황은
[`../../Crusher_Genesis/FEM/FEM.md`](../../Crusher_Genesis/FEM/FEM.md) 참고.

작성: 2026-06-30

---

## 0. 세 범주의 정의 (먼저 읽기)

데이터를 "A 실험 / B 트윈 / C 한계"로 나누는 **기준**을 명확히 한다. 특히 B의
정의가 애매하다는 지적이 있었어 — 아래처럼 못 박는다.

| 범주 | 정의 (한 줄 기준) |
|---|---|
| **A. 실험으로 얻는 값** | Crusher·정제에 **센서를 붙이거나 직접 셀 수 있는** 바깥에서 관측 가능한 양 (힘·횟수·시간·일의 *총합*) |
| **B. 트윈으로 얻어야 하는 값** | 아래 **둘 중 하나**에 해당하는 값 |
| **C. 못 얻는 값** | 실험도 시뮬도 (현재 또는 원리적으로) 줄 수 없는 양 |

**B의 정확한 정의 — 둘 중 하나면 "트윈으로 얻어야 하는" 값이다:**

1. **(내부량) 실험이 원리적으로 못 보는 것** — 정제 *내부*의 응력장 `σ_I`,
   내부 변형률, 균열 핵의 위치·시점. 실험은 표면 힘과 최종 결과(깨졌나/언제)만
   보지, "왜·어디서" 깨졌는지는 못 본다.
2. **(예측량) 실험을 돌리지 *않고* 얻고 싶은 것** — **같은 처방**의 새 형상에
   대한 `N_f`·`W*` 예측. 목적은 *실험 횟수 절약*.

> 즉 B = "실험이 **못 보거나(내부)** **보기엔 비싼(예측)** 것"을 시뮬이 채운다.
> 이 두 경우가 아니면 그냥 A(실험)로 얻는 게 맞다.

여기서 **"처방(formulation)"** = 약의 재료 레시피(주성분 + 충전제·결합제·붕해제·
활택제 비율 + 타정압). 정제의 물성(E, ν, σ_t, ρ)은 *처방*이 결정하고 *형상*과는
독립 → 한 처방을 실험 1회로 보정하면, 같은 처방의 다른 형상은 시뮬 예측만으로 커버.

---

## A. Crusher + 정제로 *직접 측정*하는 데이터 (실측)

| 데이터 | 단위 | 측정 방법 | 용도 |
|---|---|---|---|
| 모터 토크 / 전류 | N·m | 드라이버 전류 → 크랭크 힘 환산 | F_peak·일 계산의 입력 |
| 크랭크 각도·각속도 | rad, rad/s | 엔코더 | 스트로크 속도, 운동학 |
| **타격 힘 F_peak** | N | 토크 × 크랭크암, 또는 로드셀 | regime 판정 (vs F_threshold) |
| **N_f (파쇄까지 스트로크 수)** | 회 | 첫 균열까지 육안/카메라 카운트 | ✅ 가장 직접적인 트윈 검증값 |
| 파쇄까지 시간 | s | 스트로크 수 × 주기 | N_f와 등가 |
| **W_motor (모터가 한 일)** | J | ∫ τ·ω dt 적분 | W* 추정의 상한 (손실 포함) |
| 정제 경도(hardness) | N | 별도 경도시험기 | σ_c ≈ Hardness / 접촉면적 |
| **인장강도 σ_t** | Pa | Brazilian(직경방향 압축) 시험 | 파단 판정의 재료 기준값 |
| 질량 / 형상(3D scan) / 곡률 | kg, m | 저울, 스캐너 | ρ, FEM 메쉬 입력 |
| 파쇄 후 조각 크기분포 | m | 사후 체질/이미지 | 분쇄 품질(2차 지표) |

> 핵심: 실험은 **"바깥에서 보이는 양"**(힘·횟수·시간·일의 *총합*)만 준다.
> **"왜·어디서 깨졌나"** 는 못 본다.

---

## B. 트윈(FEM)으로 *얻어야* 하는 데이터 — 실험이 못 보는 내부값·예측값

| 데이터 | 단위 | B 정의 | 왜 시뮬인가 | 현재 상태 |
|---|---|---|---|---|
| **σ_I 응력장 (최대 주응력)** | Pa | ①내부 | 균열 *핵 위치·시점*은 내부 응력집중부 | ✅ 탄성 FEM |
| von Mises / 주응력 분포 | Pa | ①내부 | 파단 판정 표준, 내부값 | ✅ 후처리 |
| **F_threshold (단일타격 파쇄력)** | N | ①내부 | σ_I=σ_t 되는 peak force | 후처리 추정 |
| 내부 변형률 ε | — | ①내부 | 부위별 변형 분포 | ✅ |
| **새 형상의 N_f·W\* forward 예측** | 회 / J | ②예측 | **같은 처방** 다른 형상을 실험 없이 | 손상규칙 필요 |
| regime 분류 (I/II/III) | — | ①+② | F_peak vs F_threshold | ✅ |
| material card (E, ν, σ_t) | Pa | ②역추정 | 실험 N_f·W*로 *역보정* | 캘리브레이션 루프 |

> 핵심: 트윈은 **"안에서 일어나는 일"**(응력장·균열 시작점)과 **"실험 안 한 형상의
> 예측"**을 준다.

---

## C. *얻을 수 없는* / 현재 막힌 데이터 (한계)

| 데이터 | 이유 | 우회책 |
|---|---|---|
| **정량 반력 F(t)** (현재) | Hertz 점접촉 — 이론 대비 ~1000× 부족 (FEM.md §4.6) | 깊게 압입(면접촉) or 구속노드 반력 |
| 절대 변형에너지 [J] | `elements_el_energy` 단위 버그 ~10⁹배 (FEM.md §4.5) | node 변위로 ∇u 직접 적분 |
| **파단/손상 누적 모델** | Genesis 기본 FEM에 손상모델 **없음** | 외부 후처리, pre-fracture hack (FEM.md §4.7) |
| 파쇄 *후* 조각 거동 | 표준 FEM은 메쉬 고정 — fracture 한계 | MPM/입자법 영역 (트윈 범위 밖) |
| 속도의존 강도(rate effect) | 기본 선형탄성엔 없음 | 재료모델 확장 |
| 미시 균열 경로·화학변화 | 연속체 가정 붕괴, 물리 범위 밖 | data-driven fallback (DigitalTwin.md §9) |

---

## D. 데이터 흐름 — A로 B를 보정, B로 확장

```
A(실험: N_f, W_motor, F_peak)  ──역보정(calibration)──▶  B: material card (σ_t, E)
                                                              │
                                                        forward FEM
                                                              ▼
                                      B: 같은 처방·새 형상의 N_f·W* 예측
```

A는 **검증·보정의 ground truth**, B는 **내부 가시화 + 미실험 형상 확장**. C는
경계를 알고 우회·근사하는 영역.

---

## E. "S-N 곡선" 재검토 — 알약에 그대로 쓰면 안 된다

이전 논의에서 반복 타격 파쇄를 **S-N 곡선**으로 묘사하자는 얘기가 나왔는데,
"알약은 알루미늄·철 같은 균질 재료가 아닌데 S-N으로 보는 게 의미 있나"라는
지적이 있었다. **이 지적이 재료적으로 옳다.** 정리한다.

### E-1. 왜 금속식 S-N이 알약엔 부적절한가

| 구분 | 금속 S-N (Wöhler) | 알약(정제) |
|---|---|---|
| 재료 | 균질·연성 금속 | **압축 분말 성형체** (다공성·취성·불균질 granular compact) |
| 손상 기구 | 주기적 **소성** 손상 누적 (전위·미세균열 성장) | 충격당 **취성 미세균열 생성·합체** (소성 거의 없음) |
| cycle 수 | 10³–10⁷ (고주기 피로) | 수~수십 회 (저주기 충격 손상) |
| 곡선 의미 | **재료 상수**에 가까움 | 이 정제(처방+형상) 고유의 **현상론적 곡선** |

→ 알약에서 일어나는 건 금속 *피로*가 아니라 **반복 충격에 의한 손상 누적/분쇄
(comminution)** 다. 광물·콘크리트의 반복충격 파쇄(breakage probability, Bond work
index)에 더 가깝다.

### E-2. 그럼 무엇으로 부르고, 무엇을 측정하나

- "S-N 곡선"이라는 **이름을 버리고**, 실제로 우리가 쓰는 건
  **F_peak ↔ N_f 경험적 파쇄(breakage) 관계** (또는 *충격당 파쇄확률*)다.
  이건 **재료 상수가 아니라** 특정 정제에 대한 fit/lookup 곡선임을 명시한다.
- **진짜 재료 물성**은 따로 있고, 정제에 맞는 표준은:

  | 물성 | 측정/의미 |
  |---|---|
  | **σ_t (인장강도)** | Brazilian(직경압축) 시험 — 정제 강도의 **표준 시험** |
  | **Weibull modulus** | 취성 강도의 *산포* (불균질·결함 분포 반영) |
  | **G_c (파괴에너지)** | 단위 면적당 균열 생성 에너지 |
  | **porosity / ρ** | 타정압의 결과, 강도와 직결 |

### E-3. 트윈에서의 역할 분담 (결론)

- **FEM(B)**: 단일 타격의 `σ_I` 응력장 → `F_threshold`, 그리고 *충격당 응력*을 제공.
- **손상 누적(현상론)**: 그 응력을 입력으로 **damage rule**(예: 누적손상 D += f(σ),
  D≥1이면 파쇄)을 적용 → `N_f`. 금속 S-N이 아니라 **취성 손상누적/Weibull 기반**으로.
- **실험(A)**: `F_peak`–`N_f` 점들을 직접 찍어 위 규칙을 보정. 물리모델이 끝내
  안 닫히면, 이 점들 자체를 **data-driven 매핑**으로 쓰는 것이 한 박사님 피드백
  (DigitalTwin.md §9)의 fallback과 일치.

> 한 줄 결론: **반복 타격 거동은 "S-N 곡선(재료 상수)"이 아니라 "이 정제의
> 경험적 파쇄/손상누적 곡선"으로 봐야 한다.** 재료 고유값은 σ_t·Weibull·G_c로
> 따로 잡고, F–N_f는 그 위에 얹힌 현상론적 fit으로 취급한다.

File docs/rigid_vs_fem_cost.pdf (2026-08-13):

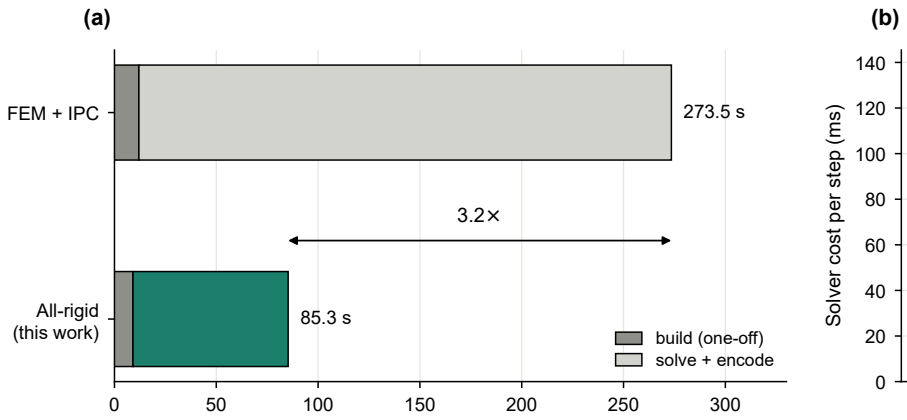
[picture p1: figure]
FEM + IPC; All-rigid (this work); build (one-off) solve + encode; Solver cost per step (ms)

Wall-clock time per run (s), 2230 steps

FEM + IPC | All-rigid

0

117.3

34.2

3

4

×

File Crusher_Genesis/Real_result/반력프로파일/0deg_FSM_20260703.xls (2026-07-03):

NO. | Time | Value | Pressure
???果: | Maximum:839N | Minimum:0N | Average:27.23N
4789 | 오후 12:51:44 | 0 N | 0.0000MPa
4788 | 오후 12:51:43 | 0 N | 0.0000MPa
4787 | 오후 12:51:43 | 0 N | 0.0000MPa
4786 | 오후 12:51:43 | 0 N | 0.0000MPa
4785 | 오후 12:51:43 | 0 N | 0.0000MPa
4784 | 오후 12:51:43 | 0 N | 0.0000MPa
4783 | 오후 12:51:42 | 0 N | 0.0000MPa
4782 | 오후 12:51:42 | 0 N | 0.0000MPa
4781 | 오후 12:51:42 | 0 N | 0.0000MPa
4780 | 오후 12:51:39 | 0 N | 0.0000MPa
4779 | 오후 12:51:39 | 0 N | 0.0000MPa
4778 | 오후 12:51:39 | 0 N | 0.0000MPa
4777 | 오후 12:51:39 | 0 N | 0.0000MPa
4776 | 오후 12:51:39 | 0 N | 0.0000MPa
4775 | 오후 12:51:39 | 0 N | 0.0000MPa
4774 | 오후 12:51:38 | 0 N | 0.0000MPa
4773 | 오후 12:51:38 | 0 N | 0.0000MPa
4772 | 오후 12:51:38 | 0 N | 0.0000MPa
4771 | 오후 12:51:38 | 0 N | 0.0000MPa
4770 | 오후 12:51:38 | 0 N | 0.0000MPa
4769 | 오후 12:51:37 | 0 N | 0.0000MPa
4768 | 오후 12:51:37 | 0 N | 0.0000MPa
4767 | 오후 12:51:37 | 0 N | 0.0000MPa
4766 | 오후 12:51:37 | 0 N | 0.0000MPa
4765 | 오후 12:51:37 | 0 N | 0.0000MPa
4764 | 오후 12:51:36 | 0 N | 0.0000MPa
4763 | 오후 12:51:36 | 0 N | 0.0000MPa
4762 | 오후 12:51:36 | 0 N | 0.0000MPa
4761 | 오후 12:51:36 | 0 N | 0.0000MPa
4760 | 오후 12:51:36 | 0 N | 0.0000MPa
4759 | 오후 12:51:35 | 0 N | 0.0000MPa
4758 | 오후 12:51:35 | 0 N | 0.0000MPa
4757 | 오후 12:51:35 | 0 N | 0.0000MPa
4756 | 오후 12:51:35 | 0 N | 0.0000MPa
4755 | 오후 12:51:35 | 0 N | 0.0000MPa
4754 | 오후 12:51:35 | 0 N | 0.0000MPa
4753 | 오후 12:51:35 | 0 N | 0.0000MPa
4752 | 오후 12:51:34 | 0 N | 0.0000MPa
4751 | 오후 12:51:34 | 0 N | 0.0000MPa
4750 | 오후 12:51:34 | 0 N | 0.0000MPa
4749 | 오후 12:51:34 | 0 N | 0.0000MPa
4748 | 오후 12:51:34 | 0 N | 0.0000MPa
4747 | 오후 12:51:34 | 0 N | 0.0000MPa
4746 | 오후 12:51:34 | 0 N | 0.0000MPa
4745 | 오후 12:51:33 | 0 N | 0.0000MPa
4744 | 오후 12:51:33 | 0 N | 0.0000MPa
4743 | 오후 12:51:33 | 0 N | 0.0000MPa
4742 | 오후 12:51:33 | 0 N | 0.0000MPa
4741 | 오후 12:51:33 | 0 N | 0.0000MPa
4740 | 오후 12:51:33 | 0 N | 0.0000MPa
4739 | 오후 12:51:33 | 0 N | 0.0000MPa
4738 | 오후 12:51:32 | 0 N | 0.0000MPa
4737 | 오후 12:51:32 | 0 N | 0.0000MPa
4736 | 오후 12:51:32 | 0 N | 0.0000MPa
4735 | 오후 12:51:32 | 0 N | 0.0000MPa
4734 | 오후 12:51:32 | 0 N | 0.0000MPa
4733 | 오후 12:51:32 | 0 N | 0.0000MPa
4732 | 오후 12:51:32 | 0 N | 0.0000MPa
4731 | 오후 12:51:32 | 0 N | 0.0000MPa
4730 | 오후 12:51:31 | 0 N | 0.0000MPa
4729 | 오후 12:51:31 | 0 N | 0.0000MPa
4728 | 오후 12:51:31 | 0 N | 0.0000MPa
4727 | 오후 12:51:31 | 0 N | 0.0000MPa
4726 | 오후 12:51:31 | 0 N | 0.0000MPa
4725 | 오후 12:51:31 | 0 N | 0.0000MPa
4724 | 오후 12:51:31 | 0 N | 0.0000MPa
4723 | 오후 12:51:30 | 0 N | 0.0000MPa
4722 | 오후 12:51:30 | 0 N | 0.0000MPa
4721 | 오후 12:51:30 | 0 N | 0.0000MPa
4720 | 오후 12:51:30 | 0 N | 0.0000MPa
4719 | 오후 12:51:30 | 0 N | 0.0000MPa
4718 | 오후 12:51:30 | 0 N | 0.0000MPa
4717 | 오후 12:51:30 | 0 N | 0.0000MPa
4716 | 오후 12:51:29 | 0 N | 0.0000MPa
4715 | 오후 12:51:29 | 0 N | 0.0000MPa
4714 | 오후 12:51:27 | 0 N | 0.0000MPa
4713 | 오후 12:51:27 | 0 N | 0.0000MPa
4712 | 오후 12:51:27 | 0 N | 0.0000MPa
4711 | 오후 12:51:26 | 0 N | 0.0000MPa
4710 | 오후 12:51:26 | 0 N | 0.0000MPa
4709 | 오후 12:51:26 | 0 N | 0.0000MPa
4708 | 오후 12:51:26 | 0 N | 0.0000MPa
4707 | 오후 12:51:26 | 0 N | 0.0000MPa
4706 | 오후 12:51:26 | 0 N | 0.0000MPa
4705 | 오후 12:51:25 | 0 N | 0.0000MPa
4704 | 오후 12:51:25 | 0 N | 0.0000MPa
4703 | 오후 12:51:25 | 0 N | 0.0000MPa
4702 | 오후 12:51:25 | 0 N | 0.0000MPa
4701 | 오후 12:51:25 | 0 N | 0.0000MPa
4700 | 오후 12:51:24 | 0 N | 0.0000MPa
4699 | 오후 12:51:24 | 0 N | 0.0000MPa
4698 | 오후 12:51:24 | 0 N | 0.0000MPa
4697 | 오후 12:51:24 | 0 N | 0.0000MPa
4696 | 오후 12:51:24 | 0 N | 0.0000MPa
4695 | 오후 12:51:23 | 0 N | 0.0000MPa
4694 | 오후 12:51:23 | 0 N | 0.0000MPa
4693 | 오후 12:51:23 | 0 N | 0.0000MPa
4692 | 오후 12:51:23 | 0 N | 0.0000MPa
4691 | 오후 12:51:23 | 0 N | 0.0000MPa
4690 | 오후 12:51:23 | 0 N | 0.0000MPa
4689 | 오후 12:51:22 | 0 N | 0.0000MPa
4688 | 오후 12:51:22 | 0 N | 0.0000MPa
4687 | 오후 12:51:22 | 0 N | 0.0000MPa
4686 | 오후 12:51:22 | 0 N | 0.0000MPa
4685 | 오후 12:51:22 | 0 N | 0.0000MPa
4684 | 오후 12:51:21 | 0 N | 0.0000MPa
4683 | 오후 12:51:21 | 0 N | 0.0000MPa
4682 | 오후 12:51:21 | 0 N | 0.0000MPa
4681 | 오후 12:51:21 | 0 N | 0.0000MPa
4680 | 오후 12:51:21 | 0 N | 0.0000MPa
4679 | 오후 12:51:20 | 0 N | 0.0000MPa
4678 | 오후 12:51:20 | 0 N | 0.0000MPa
4677 | 오후 12:51:20 | 0 N | 0.0000MPa
4676 | 오후 12:51:20 | 0 N | 0.0000MPa
4675 | 오후 12:51:20 | 0 N | 0.0000MPa
4674 | 오후 12:51:20 | 0 N | 0.0000MPa
4673 | 오후 12:51:19 | 0 N | 0.0000MPa
4672 | 오후 12:51:19 | 0 N | 0.0000MPa
4671 | 오후 12:51:19 | 0 N | 0.0000MPa
4670 | 오후 12:51:19 | 0 N | 0.0000MPa
4669 | 오후 12:51:19 | 0 N | 0.0000MPa
4668 | 오후 12:51:18 | 0 N | 0.0000MPa
4667 | 오후 12:51:18 | 0 N | 0.0000MPa
4666 | 오후 12:51:18 | 0 N | 0.0000MPa
4665 | 오후 12:51:18 | 0 N | 0.0000MPa
4664 | 오후 12:51:18 | 0 N | 0.0000MPa
4663 | 오후 12:51:17 | 0 N | 0.0000MPa
4662 | 오후 12:51:17 | 0 N | 0.0000MPa
4661 | 오후 12:51:17 | 0 N | 0.0000MPa
4660 | 오후 12:51:17 | 0 N | 0.0000MPa
4659 | 오후 12:51:17 | 0 N | 0.0000MPa
4658 | 오후 12:51:16 | 0 N | 0.0000MPa
4657 | 오후 12:51:16 | 0 N | 0.0000MPa
4656 | 오후 12:51:16 | 0 N | 0.0000MPa
4655 | 오후 12:51:16 | 0 N | 0.0000MPa
4654 | 오후 12:51:16 | 0 N | 0.0000MPa
4653 | 오후 12:51:16 | 0 N | 0.0000MPa
4652 | 오후 12:51:15 | 0 N | 0.0000MPa
4651 | 오후 12:51:15 | 0 N | 0.0000MPa
4650 | 오후 12:51:15 | 0 N | 0.0000MPa
4649 | 오후 12:51:15 | 0 N | 0.0000MPa
4648 | 오후 12:51:15 | 0 N | 0.0000MPa
4647 | 오후 12:51:14 | 0 N | 0.0000MPa
4646 | 오후 12:51:14 | 0 N | 0.0000MPa
4645 | 오후 12:51:14 | 0 N | 0.0000MPa
4644 | 오후 12:51:14 | 0 N | 0.0000MPa
4643 | 오후 12:51:14 | 0 N | 0.0000MPa
4642 | 오후 12:51:13 | 0 N | 0.0000MPa
4641 | 오후 12:51:13 | 0 N | 0.0000MPa
4640 | 오후 12:51:13 | 0 N | 0.0000MPa
4639 | 오후 12:51:13 | 0 N | 0.0000MPa
4638 | 오후 12:51:13 | 0 N | 0.0000MPa
4637 | 오후 12:51:13 | 0 N | 0.0000MPa
4636 | 오후 12:51:12 | 0 N | 0.0000MPa
4635 | 오후 12:51:12 | 0 N | 0.0000MPa
4634 | 오후 12:51:12 | 0 N | 0.0000MPa
4633 | 오후 12:51:12 | 0 N | 0.0000MPa
4632 | 오후 12:51:12 | 0 N | 0.0000MPa
4631 | 오후 12:51:11 | 0 N | 0.0000MPa
4630 | 오후 12:51:11 | 0 N | 0.0000MPa
4629 | 오후 12:51:11 | 0 N | 0.0000MPa
4628 | 오후 12:51:11 | 0 N | 0.0000MPa
4627 | 오후 12:51:11 | 0 N | 0.0000MPa
4626 | 오후 12:51:10 | 0 N | 0.0000MPa
4625 | 오후 12:51:10 | 0 N | 0.0000MPa
4624 | 오후 12:51:10 | 0 N | 0.0000MPa
4623 | 오후 12:51:10 | 0 N | 0.0000MPa
4622 | 오후 12:51:10 | 0 N | 0.0000MPa
4621 | 오후 12:51:10 | 0 N | 0.0000MPa
4620 | 오후 12:51:09 | 0 N | 0.0000MPa
4619 | 오후 12:51:09 | 0 N | 0.0000MPa
4618 | 오후 12:51:09 | 0 N | 0.0000MPa
4617 | 오후 12:51:09 | 0 N | 0.0000MPa
4616 | 오후 12:51:09 | 0 N | 0.0000MPa
4615 | 오후 12:51:08 | 0 N | 0.0000MPa
4614 | 오후 12:51:08 | 0 N | 0.0000MPa
4613 | 오후 12:51:08 | 0 N | 0.0000MPa
4612 | 오후 12:51:08 | 0 N | 0.0000MPa
4611 | 오후 12:51:08 | 0 N | 0.0000MPa
4610 | 오후 12:51:07 | 0 N | 0.0000MPa
4609 | 오후 12:51:07 | 0 N | 0.0000MPa
4608 | 오후 12:51:07 | 0 N | 0.0000MPa
4607 | 오후 12:51:07 | 0 N | 0.0000MPa
4606 | 오후 12:51:07 | 0 N | 0.0000MPa
4605 | 오후 12:51:07 | 0 N | 0.0000MPa
4604 | 오후 12:51:06 | 0 N | 0.0000MPa
4603 | 오후 12:51:06 | 0 N | 0.0000MPa
4602 | 오후 12:51:06 | 0 N | 0.0000MPa
4601 | 오후 12:51:06 | 0 N | 0.0000MPa
4600 | 오후 12:51:06 | 0 N | 0.0000MPa
4599 | 오후 12:51:06 | 0 N | 0.0000MPa
4598 | 오후 12:51:06 | 0 N | 0.0000MPa
4597 | 오후 12:51:05 | 0 N | 0.0000MPa
4596 | 오후 12:51:05 | 0 N | 0.0000MPa
4595 | 오후 12:51:05 | 0 N | 0.0000MPa
4594 | 오후 12:51:05 | 0 N | 0.0000MPa
4593 | 오후 12:51:05 | 0 N | 0.0000MPa
4592 | 오후 12:51:05 | 0 N | 0.0000MPa
4591 | 오후 12:51:05 | 0 N | 0.0000MPa
4590 | 오후 12:51:04 | 0 N | 0.0000MPa
4589 | 오후 12:51:04 | 0 N | 0.0000MPa
4588 | 오후 12:51:04 | 0 N | 0.0000MPa
4587 | 오후 12:51:04 | 0 N | 0.0000MPa
4586 | 오후 12:51:04 | 0 N | 0.0000MPa
4585 | 오후 12:51:04 | 0 N | 0.0000MPa
4584 | 오후 12:51:04 | 0 N | 0.0000MPa
4583 | 오후 12:51:04 | 0 N | 0.0000MPa
4582 | 오후 12:51:03 | 0 N | 0.0000MPa
4581 | 오후 12:51:03 | 0 N | 0.0000MPa
4580 | 오후 12:51:03 | 0 N | 0.0000MPa
4579 | 오후 12:51:03 | 0 N | 0.0000MPa
4578 | 오후 12:51:03 | 0 N | 0.0000MPa
4577 | 오후 12:51:03 | 0 N | 0.0000MPa
4576 | 오후 12:51:02 | 0 N | 0.0000MPa
4575 | 오후 12:51:02 | 0 N | 0.0000MPa
4574 | 오후 12:51:02 | 0 N | 0.0000MPa
4573 | 오후 12:51:02 | 0 N | 0.0000MPa
4572 | 오후 12:51:00 | 0 N | 0.0000MPa
4571 | 오후 12:51:00 | 0 N | 0.0000MPa
4570 | 오후 12:51:00 | 0 N | 0.0000MPa
4569 | 오후 12:51:00 | 0 N | 0.0000MPa
4568 | 오후 12:51:00 | 0 N | 0.0000MPa
4567 | 오후 12:50:59 | 0 N | 0.0000MPa
4566 | 오후 12:50:59 | 0 N | 0.0000MPa
4565 | 오후 12:50:59 | 0 N | 0.0000MPa
4564 | 오후 12:50:59 | 0 N | 0.0000MPa
4563 | 오후 12:50:59 | 0 N | 0.0000MPa
4562 | 오후 12:50:58 | 0 N | 0.0000MPa
4561 | 오후 12:50:58 | 0 N | 0.0000MPa
4560 | 오후 12:50:58 | 0 N | 0.0000MPa
4559 | 오후 12:50:58 | 0 N | 0.0000MPa
4558 | 오후 12:50:58 | 0 N | 0.0000MPa
4557 | 오후 12:50:57 | 0 N | 0.0000MPa
4556 | 오후 12:50:57 | 0 N | 0.0000MPa
4555 | 오후 12:50:57 | 0 N | 0.0000MPa
4554 | 오후 12:50:57 | 0 N | 0.0000MPa
4553 | 오후 12:50:57 | 0 N | 0.0000MPa
4552 | 오후 12:50:57 | 0 N | 0.0000MPa
4551 | 오후 12:50:56 | 0 N | 0.0000MPa
4550 | 오후 12:50:56 | 0 N | 0.0000MPa
4549 | 오후 12:50:56 | 0 N | 0.0000MPa
4548 | 오후 12:50:56 | 0 N | 0.0000MPa
4547 | 오후 12:50:56 | 0 N | 0.0000MPa
4546 | 오후 12:50:55 | 0 N | 0.0000MPa
4545 | 오후 12:50:55 | 0 N | 0.0000MPa
4544 | 오후 12:50:55 | 0 N | 0.0000MPa
4543 | 오후 12:50:55 | 0 N | 0.0000MPa
4542 | 오후 12:50:55 | 0 N | 0.0000MPa
4541 | 오후 12:50:54 | 0 N | 0.0000MPa
4540 | 오후 12:50:54 | 0 N | 0.0000MPa
4539 | 오후 12:50:54 | 0 N | 0.0000MPa
4538 | 오후 12:50:54 | 0 N | 0.0000MPa
4537 | 오후 12:50:54 | 0 N | 0.0000MPa
4536 | 오후 12:50:54 | 0 N | 0.0000MPa
4535 | 오후 12:50:53 | 0 N | 0.0000MPa
4534 | 오후 12:50:53 | 0 N | 0.0000MPa
4533 | 오후 12:50:53 | 0 N | 0.0000MPa
4532 | 오후 12:50:53 | 0 N | 0.0000MPa
4531 | 오후 12:50:53 | 0 N | 0.0000MPa
4530 | 오후 12:50:52 | 0 N | 0.0000MPa
4529 | 오후 12:50:52 | 0 N | 0.0000MPa
4528 | 오후 12:50:52 | 0 N | 0.0000MPa
4527 | 오후 12:50:52 | 0 N | 0.0000MPa
4526 | 오후 12:50:52 | 0 N | 0.0000MPa
4525 | 오후 12:50:51 | 0 N | 0.0000MPa
4524 | 오후 12:50:51 | 0 N | 0.0000MPa
4523 | 오후 12:50:51 | 0 N | 0.0000MPa
4522 | 오후 12:50:51 | 0 N | 0.0000MPa
4521 | 오후 12:50:51 | 0 N | 0.0000MPa
4520 | 오후 12:50:51 | 0 N | 0.0000MPa
4519 | 오후 12:50:50 | 0 N | 0.0000MPa
4518 | 오후 12:50:50 | 0 N | 0.0000MPa
4517 | 오후 12:50:50 | 0 N | 0.0000MPa
4516 | 오후 12:50:50 | 0 N | 0.0000MPa
4515 | 오후 12:50:50 | 0 N | 0.0000MPa
4514 | 오후 12:50:49 | 0 N | 0.0000MPa
4513 | 오후 12:50:49 | 0 N | 0.0000MPa
4512 | 오후 12:50:49 | 0 N | 0.0000MPa
4511 | 오후 12:50:49 | 0 N | 0.0000MPa
4510 | 오후 12:50:49 | 0 N | 0.0000MPa
4509 | 오후 12:50:48 | 0 N | 0.0000MPa
4508 | 오후 12:50:48 | 0 N | 0.0000MPa
4507 | 오후 12:50:48 | 0 N | 0.0000MPa
4506 | 오후 12:50:48 | 0 N | 0.0000MPa
4505 | 오후 12:50:48 | 0 N | 0.0000MPa
4504 | 오후 12:50:48 | 0 N | 0.0000MPa
4503 | 오후 12:50:47 | 0 N | 0.0000MPa
4502 | 오후 12:50:47 | 0 N | 0.0000MPa
4501 | 오후 12:50:47 | 0 N | 0.0000MPa
4500 | 오후 12:50:47 | 0 N | 0.0000MPa
4499 | 오후 12:50:47 | 0 N | 0.0000MPa
4498 | 오후 12:50:46 | 0 N | 0.0000MPa
4497 | 오후 12:50:46 | 0 N | 0.0000MPa
4496 | 오후 12:50:46 | 0 N | 0.0000MPa
4495 | 오후 12:50:46 | 0 N | 0.0000MPa
4494 | 오후 12:50:46 | 0 N | 0.0000MPa
4493 | 오후 12:50:45 | 0 N | 0.0000MPa
4492 | 오후 12:50:45 | 0 N | 0.0000MPa
4491 | 오후 12:50:45 | 0 N | 0.0000MPa
4490 | 오후 12:50:45 | 0 N | 0.0000MPa
4489 | 오후 12:50:45 | 0 N | 0.0000MPa
4488 | 오후 12:50:45 | 0 N | 0.0000MPa
4487 | 오후 12:50:44 | 0 N | 0.0000MPa
4486 | 오후 12:50:44 | 0 N | 0.0000MPa
4485 | 오후 12:50:44 | 0 N | 0.0000MPa
4484 | 오후 12:50:44 | 0 N | 0.0000MPa
4483 | 오후 12:50:44 | 0 N | 0.0000MPa
4482 | 오후 12:50:43 | 0 N | 0.0000MPa
4481 | 오후 12:50:43 | 0 N | 0.0000MPa
4480 | 오후 12:50:43 | 0 N | 0.0000MPa
4479 | 오후 12:50:43 | 0 N | 0.0000MPa
4478 | 오후 12:50:43 | 0 N | 0.0000MPa
4477 | 오후 12:50:42 | 0 N | 0.0000MPa
4476 | 오후 12:50:42 | 0 N | 0.0000MPa
4475 | 오후 12:50:42 | 0 N | 0.0000MPa
4474 | 오후 12:50:42 | 0 N | 0.0000MPa
4473 | 오후 12:50:42 | 0 N | 0.0000MPa
4472 | 오후 12:50:41 | 0 N | 0.0000MPa
4471 | 오후 12:50:41 | 0 N | 0.0000MPa
4470 | 오후 12:50:41 | 0 N | 0.0000MPa
4469 | 오후 12:50:41 | 0 N | 0.0000MPa
4468 | 오후 12:50:41 | 0 N | 0.0000MPa
4467 | 오후 12:50:41 | 0 N | 0.0000MPa
4466 | 오후 12:50:40 | 0 N | 0.0000MPa
4465 | 오후 12:50:40 | 0 N | 0.0000MPa
4464 | 오후 12:50:40 | 0 N | 0.0000MPa
4463 | 오후 12:50:40 | 0 N | 0.0000MPa
4462 | 오후 12:50:40 | 0 N | 0.0000MPa
4461 | 오후 12:50:39 | 0 N | 0.0000MPa
4460 | 오후 12:50:39 | 0 N | 0.0000MPa
4459 | 오후 12:50:39 | 0 N | 0.0000MPa
4458 | 오후 12:50:39 | 0 N | 0.0000MPa
4457 | 오후 12:50:39 | 0 N | 0.0000MPa
4456 | 오후 12:50:38 | 0 N | 0.0000MPa
4455 | 오후 12:50:38 | 0 N | 0.0000MPa
4454 | 오후 12:50:38 | 0 N | 0.0000MPa
4453 | 오후 12:50:38 | 0 N | 0.0000MPa
4452 | 오후 12:50:38 | 0 N | 0.0000MPa
4451 | 오후 12:50:38 | 0 N | 0.0000MPa
4450 | 오후 12:50:37 | 0 N | 0.0000MPa
4449 | 오후 12:50:37 | 0 N | 0.0000MPa
4448 | 오후 12:50:37 | 0 N | 0.0000MPa
4447 | 오후 12:50:37 | 0 N | 0.0000MPa
4446 | 오후 12:50:37 | 0 N | 0.0000MPa
4445 | 오후 12:50:36 | 0 N | 0.0000MPa
4444 | 오후 12:50:36 | 0 N | 0.0000MPa
4443 | 오후 12:50:36 | 0 N | 0.0000MPa
4442 | 오후 12:50:36 | 0 N | 0.0000MPa
4441 | 오후 12:50:36 | 0 N | 0.0000MPa
4440 | 오후 12:50:35 | 0 N | 0.0000MPa
4439 | 오후 12:50:35 | 0 N | 0.0000MPa
4438 | 오후 12:50:35 | 0 N | 0.0000MPa
4437 | 오후 12:50:35 | 0 N | 0.0000MPa
4436 | 오후 12:50:35 | 0 N | 0.0000MPa
4435 | 오후 12:50:35 | 0 N | 0.0000MPa
4434 | 오후 12:50:34 | 0 N | 0.0000MPa
4433 | 오후 12:50:34 | 0 N | 0.0000MPa
4432 | 오후 12:50:34 | 0 N | 0.0000MPa
4431 | 오후 12:50:34 | 0 N | 0.0000MPa
4430 | 오후 12:50:34 | 0 N | 0.0000MPa
4429 | 오후 12:50:33 | 0 N | 0.0000MPa
4428 | 오후 12:50:33 | 0 N | 0.0000MPa
4427 | 오후 12:50:33 | 0 N | 0.0000MPa
4426 | 오후 12:50:33 | 0 N | 0.0000MPa
4425 | 오후 12:50:33 | 0 N | 0.0000MPa
4424 | 오후 12:50:32 | 0 N | 0.0000MPa
4423 | 오후 12:50:32 | 0 N | 0.0000MPa
4422 | 오후 12:50:32 | 0 N | 0.0000MPa
4421 | 오후 12:50:32 | 0 N | 0.0000MPa
4420 | 오후 12:50:32 | 0 N | 0.0000MPa
4419 | 오후 12:50:32 | 0 N | 0.0000MPa
4418 | 오후 12:50:31 | 0 N | 0.0000MPa
4417 | 오후 12:50:31 | 0 N | 0.0000MPa
4416 | 오후 12:50:31 | 0 N | 0.0000MPa
4415 | 오후 12:50:31 | 0 N | 0.0000MPa
4414 | 오후 12:50:31 | 0 N | 0.0000MPa
4413 | 오후 12:50:30 | 0 N | 0.0000MPa
4412 | 오후 12:50:30 | 0 N | 0.0000MPa
4411 | 오후 12:50:30 | 0 N | 0.0000MPa
4410 | 오후 12:50:30 | 0 N | 0.0000MPa
4409 | 오후 12:50:30 | 0 N | 0.0000MPa
4408 | 오후 12:50:29 | 0 N | 0.0000MPa
4407 | 오후 12:50:29 | 0 N | 0.0000MPa
4406 | 오후 12:50:29 | 0 N | 0.0000MPa
4405 | 오후 12:50:29 | 0 N | 0.0000MPa
4404 | 오후 12:50:29 | 0 N | 0.0000MPa
4403 | 오후 12:50:29 | 0 N | 0.0000MPa
4402 | 오후 12:50:28 | 0 N | 0.0000MPa
4401 | 오후 12:50:28 | 0 N | 0.0000MPa
4400 | 오후 12:50:28 | 0 N | 0.0000MPa
4399 | 오후 12:50:28 | 0 N | 0.0000MPa
4398 | 오후 12:50:28 | 0 N | 0.0000MPa
4397 | 오후 12:50:27 | 0 N | 0.0000MPa
4396 | 오후 12:50:27 | 0 N | 0.0000MPa
4395 | 오후 12:50:27 | 0 N | 0.0000MPa
4394 | 오후 12:50:27 | 0 N | 0.0000MPa
4393 | 오후 12:50:27 | 0 N | 0.0000MPa
4392 | 오후 12:50:26 | 0 N | 0.0000MPa
4391 | 오후 12:50:26 | 0 N | 0.0000MPa
4390 | 오후 12:50:26 | 0 N | 0.0000MPa
4389 | 오후 12:50:26 | 0 N | 0.0000MPa
4388 | 오후 12:50:26 | 0 N | 0.0000MPa
4387 | 오후 12:50:26 | 0 N | 0.0000MPa
4386 | 오후 12:50:25 | 0 N | 0.0000MPa
4385 | 오후 12:50:25 | 0 N | 0.0000MPa
4384 | 오후 12:50:25 | 0 N | 0.0000MPa
4383 | 오후 12:50:25 | 0 N | 0.0000MPa
4382 | 오후 12:50:25 | 0 N | 0.0000MPa
4381 | 오후 12:50:24 | 0 N | 0.0000MPa
4380 | 오후 12:50:24 | 0 N | 0.0000MPa
4379 | 오후 12:50:24 | 0 N | 0.0000MPa
4378 | 오후 12:50:24 | 0 N | 0.0000MPa
4377 | 오후 12:50:24 | 0 N | 0.0000MPa
4376 | 오후 12:50:23 | 0 N | 0.0000MPa
4375 | 오후 12:50:23 | 0 N | 0.0000MPa
4374 | 오후 12:50:23 | 0 N | 0.0000MPa
4373 | 오후 12:50:23 | 0 N | 0.0000MPa
4372 | 오후 12:50:23 | 0 N | 0.0000MPa
4371 | 오후 12:50:22 | 0 N | 0.0000MPa
4370 | 오후 12:50:22 | 0 N | 0.0000MPa
4369 | 오후 12:50:22 | 0 N | 0.0000MPa
4368 | 오후 12:50:22 | 0 N | 0.0000MPa
4367 | 오후 12:50:22 | 0 N | 0.0000MPa
4366 | 오후 12:50:22 | 0 N | 0.0000MPa
4365 | 오후 12:50:21 | 0 N | 0.0000MPa
4364 | 오후 12:50:21 | 0 N | 0.0000MPa
4363 | 오후 12:50:21 | 0 N | 0.0000MPa
4362 | 오후 12:50:21 | 0 N | 0.0000MPa
4361 | 오후 12:50:21 | 0 N | 0.0000MPa
4360 | 오후 12:50:20 | 0 N | 0.0000MPa
4359 | 오후 12:50:20 | 0 N | 0.0000MPa
4358 | 오후 12:50:20 | 0 N | 0.0000MPa
4357 | 오후 12:50:20 | 0 N | 0.0000MPa
4356 | 오후 12:50:20 | 0 N | 0.0000MPa
4355 | 오후 12:50:19 | 0 N | 0.0000MPa
4354 | 오후 12:50:19 | 0 N | 0.0000MPa
4353 | 오후 12:50:19 | 0 N | 0.0000MPa
4352 | 오후 12:50:19 | 0 N | 0.0000MPa
4351 | 오후 12:50:19 | 0 N | 0.0000MPa
4350 | 오후 12:50:19 | 0 N | 0.0000MPa
4349 | 오후 12:50:18 | 0 N | 0.0000MPa
4348 | 오후 12:50:18 | 0 N | 0.0000MPa
4347 | 오후 12:50:18 | 0 N | 0.0000MPa
4346 | 오후 12:50:18 | 0 N | 0.0000MPa
4345 | 오후 12:50:18 | 0 N | 0.0000MPa
4344 | 오후 12:50:17 | 0 N | 0.0000MPa
4343 | 오후 12:50:17 | 0 N | 0.0000MPa
4342 | 오후 12:50:17 | 0 N | 0.0000MPa
4341 | 오후 12:50:17 | 0 N | 0.0000MPa
4340 | 오후 12:50:17 | 0 N | 0.0000MPa
4339 | 오후 12:50:16 | 0 N | 0.0000MPa
4338 | 오후 12:50:16 | 0 N | 0.0000MPa
4337 | 오후 12:50:16 | 0 N | 0.0000MPa
4336 | 오후 12:50:16 | 0 N | 0.0000MPa
4335 | 오후 12:50:16 | 0 N | 0.0000MPa
4334 | 오후 12:50:16 | 0 N | 0.0000MPa
4333 | 오후 12:50:15 | 0 N | 0.0000MPa
4332 | 오후 12:50:15 | 0 N | 0.0000MPa
4331 | 오후 12:50:15 | 0 N | 0.0000MPa
4330 | 오후 12:50:15 | 0 N | 0.0000MPa
4329 | 오후 12:50:15 | 0 N | 0.0000MPa
4328 | 오후 12:50:14 | 0 N | 0.0000MPa
4327 | 오후 12:50:14 | 0 N | 0.0000MPa
4326 | 오후 12:50:14 | 0 N | 0.0000MPa
4325 | 오후 12:50:14 | 0 N | 0.0000MPa
4324 | 오후 12:50:14 | 0 N | 0.0000MPa
4323 | 오후 12:50:13 | 0 N | 0.0000MPa
4322 | 오후 12:50:13 | 0 N | 0.0000MPa
4321 | 오후 12:50:13 | 0 N | 0.0000MPa
4320 | 오후 12:50:13 | 0 N | 0.0000MPa
4319 | 오후 12:50:13 | 0 N | 0.0000MPa
4318 | 오후 12:50:12 | 0 N | 0.0000MPa
4317 | 오후 12:50:12 | 0 N | 0.0000MPa
4316 | 오후 12:50:12 | 0 N | 0.0000MPa
4315 | 오후 12:50:12 | 0 N | 0.0000MPa
4314 | 오후 12:50:12 | 0 N | 0.0000MPa
4313 | 오후 12:50:12 | 0 N | 0.0000MPa
4312 | 오후 12:50:11 | 0 N | 0.0000MPa
4311 | 오후 12:50:11 | 0 N | 0.0000MPa
4310 | 오후 12:50:11 | 0 N | 0.0000MPa
4309 | 오후 12:50:11 | 0 N | 0.0000MPa
4308 | 오후 12:50:11 | 0 N | 0.0000MPa
4307 | 오후 12:50:10 | 0 N | 0.0000MPa
4306 | 오후 12:50:10 | 0 N | 0.0000MPa
4305 | 오후 12:50:10 | 0 N | 0.0000MPa
4304 | 오후 12:50:10 | 0 N | 0.0000MPa
4303 | 오후 12:50:10 | 0 N | 0.0000MPa
4302 | 오후 12:50:09 | 0 N | 0.0000MPa
4301 | 오후 12:50:09 | 0 N | 0.0000MPa
4300 | 오후 12:50:09 | 0 N | 0.0000MPa
4299 | 오후 12:50:09 | 0 N | 0.0000MPa
4298 | 오후 12:50:09 | 0 N | 0.0000MPa
4297 | 오후 12:50:09 | 0 N | 0.0000MPa
4296 | 오후 12:50:08 | 0 N | 0.0000MPa
4295 | 오후 12:50:08 | 0 N | 0.0000MPa
4294 | 오후 12:50:08 | 0 N | 0.0000MPa
4293 | 오후 12:50:08 | 0 N | 0.0000MPa
4292 | 오후 12:50:08 | 0 N | 0.0000MPa
4291 | 오후 12:50:07 | 0 N | 0.0000MPa
4290 | 오후 12:50:07 | 0 N | 0.0000MPa
4289 | 오후 12:50:07 | 0 N | 0.0000MPa
4288 | 오후 12:50:07 | 0 N | 0.0000MPa
4287 | 오후 12:50:07 | 0 N | 0.0000MPa
4286 | 오후 12:50:06 | 0 N | 0.0000MPa
4285 | 오후 12:50:06 | 0 N | 0.0000MPa
4284 | 오후 12:50:06 | 0 N | 0.0000MPa
4283 | 오후 12:50:06 | 0 N | 0.0000MPa
4282 | 오후 12:50:06 | 0 N | 0.0000MPa
4281 | 오후 12:50:06 | 0 N | 0.0000MPa
4280 | 오후 12:50:05 | 0 N | 0.0000MPa
4279 | 오후 12:50:05 | 0 N | 0.0000MPa
4278 | 오후 12:50:05 | 0 N | 0.0000MPa
4277 | 오후 12:50:05 | 0 N | 0.0000MPa
4276 | 오후 12:50:05 | 0 N | 0.0000MPa
4275 | 오후 12:50:04 | 0 N | 0.0000MPa
4274 | 오후 12:50:04 | 0 N | 0.0000MPa
4273 | 오후 12:50:04 | 0 N | 0.0000MPa
4272 | 오후 12:50:04 | 0 N | 0.0000MPa
4271 | 오후 12:50:04 | 0 N | 0.0000MPa
4270 | 오후 12:50:03 | 0 N | 0.0000MPa
4269 | 오후 12:50:03 | 0 N | 0.0000MPa
4268 | 오후 12:50:03 | 0 N | 0.0000MPa
4267 | 오후 12:50:03 | 0 N | 0.0000MPa
4266 | 오후 12:50:03 | 0 N | 0.0000MPa
4265 | 오후 12:50:03 | 0 N | 0.0000MPa
4264 | 오후 12:50:02 | 0 N | 0.0000MPa
4263 | 오후 12:50:02 | 0 N | 0.0000MPa
4262 | 오후 12:50:02 | 0 N | 0.0000MPa
4261 | 오후 12:50:02 | 0 N | 0.0000MPa
4260 | 오후 12:50:02 | 0 N | 0.0000MPa
4259 | 오후 12:50:01 | 0 N | 0.0000MPa
4258 | 오후 12:50:01 | 0 N | 0.0000MPa
4257 | 오후 12:50:01 | 0 N | 0.0000MPa
4256 | 오후 12:50:01 | 0 N | 0.0000MPa
4255 | 오후 12:50:01 | 0 N | 0.0000MPa
4254 | 오후 12:50:00 | 0 N | 0.0000MPa
4253 | 오후 12:50:00 | 0 N | 0.0000MPa
4252 | 오후 12:50:00 | 0 N | 0.0000MPa
4251 | 오후 12:50:00 | 0 N | 0.0000MPa
4250 | 오후 12:50:00 | 0 N | 0.0000MPa
4249 | 오후 12:50:00 | 0 N | 0.0000MPa
4248 | 오후 12:49:59 | 0 N | 0.0000MPa
4247 | 오후 12:49:59 | 0 N | 0.0000MPa
4246 | 오후 12:49:59 | 0 N | 0.0000MPa
4245 | 오후 12:49:59 | 0 N | 0.0000MPa
4244 | 오후 12:49:59 | 0 N | 0.0000MPa
4243 | 오후 12:49:58 | 0 N | 0.0000MPa
4242 | 오후 12:49:58 | 0 N | 0.0000MPa
4241 | 오후 12:49:58 | 0 N | 0.0000MPa
4240 | 오후 12:49:58 | 0 N | 0.0000MPa
4239 | 오후 12:49:58 | 0 N | 0.0000MPa
4238 | 오후 12:49:57 | 0 N | 0.0000MPa
4237 | 오후 12:49:57 | 0 N | 0.0000MPa
4236 | 오후 12:49:57 | 0 N | 0.0000MPa
4235 | 오후 12:49:57 | 0 N | 0.0000MPa
4234 | 오후 12:49:57 | 0 N | 0.0000MPa
4233 | 오후 12:49:57 | 0 N | 0.0000MPa
4232 | 오후 12:49:56 | 0 N | 0.0000MPa
4231 | 오후 12:49:56 | 0 N | 0.0000MPa
4230 | 오후 12:49:56 | 0 N | 0.0000MPa
4229 | 오후 12:49:56 | 0 N | 0.0000MPa
4228 | 오후 12:49:56 | 0 N | 0.0000MPa
4227 | 오후 12:49:55 | 0 N | 0.0000MPa
4226 | 오후 12:49:55 | 0 N | 0.0000MPa
4225 | 오후 12:49:55 | 0 N | 0.0000MPa
4224 | 오후 12:49:55 | 0 N | 0.0000MPa
4223 | 오후 12:49:55 | 0 N | 0.0000MPa
4222 | 오후 12:49:54 | 0 N | 0.0000MPa
4221 | 오후 12:49:54 | 0 N | 0.0000MPa
4220 | 오후 12:49:54 | 0 N | 0.0000MPa
4219 | 오후 12:49:54 | 0 N | 0.0000MPa
4218 | 오후 12:49:54 | 0 N | 0.0000MPa
4217 | 오후 12:49:54 | 0 N | 0.0000MPa
4216 | 오후 12:49:53 | 0 N | 0.0000MPa
4215 | 오후 12:49:53 | 0 N | 0.0000MPa
4214 | 오후 12:49:53 | 0 N | 0.0000MPa
4213 | 오후 12:49:53 | 0 N | 0.0000MPa
4212 | 오후 12:49:53 | 0 N | 0.0000MPa
4211 | 오후 12:49:52 | 0 N | 0.0000MPa
4210 | 오후 12:49:52 | 0 N | 0.0000MPa
4209 | 오후 12:49:52 | 0 N | 0.0000MPa
4208 | 오후 12:49:52 | 0 N | 0.0000MPa
4207 | 오후 12:49:52 | 0 N | 0.0000MPa
4206 | 오후 12:49:51 | 0 N | 0.0000MPa
4205 | 오후 12:49:51 | 0 N | 0.0000MPa
4204 | 오후 12:49:51 | 0 N | 0.0000MPa
4203 | 오후 12:49:51 | 0 N | 0.0000MPa
4202 | 오후 12:49:51 | 0 N | 0.0000MPa
4201 | 오후 12:49:51 | 0 N | 0.0000MPa
4200 | 오후 12:49:50 | 0 N | 0.0000MPa
4199 | 오후 12:49:50 | 0 N | 0.0000MPa
4198 | 오후 12:49:50 | 0 N | 0.0000MPa
4197 | 오후 12:49:50 | 0 N | 0.0000MPa
4196 | 오후 12:49:50 | 0 N | 0.0000MPa
4195 | 오후 12:49:49 | 0 N | 0.0000MPa
4194 | 오후 12:49:49 | 0 N | 0.0000MPa
4193 | 오후 12:49:49 | 0 N | 0.0000MPa
4192 | 오후 12:49:49 | 0 N | 0.0000MPa
4191 | 오후 12:49:49 | 0 N | 0.0000MPa
4190 | 오후 12:49:48 | 0 N | 0.0000MPa
4189 | 오후 12:49:48 | 0 N | 0.0000MPa
4188 | 오후 12:49:48 | 0 N | 0.0000MPa
4187 | 오후 12:49:48 | 0 N | 0.0000MPa
4186 | 오후 12:49:48 | 0 N | 0.0000MPa
4185 | 오후 12:49:47 | 0 N | 0.0000MPa
4184 | 오후 12:49:47 | 0 N | 0.0000MPa
4183 | 오후 12:49:47 | 0 N | 0.0000MPa
4182 | 오후 12:49:47 | 0 N | 0.0000MPa
4181 | 오후 12:49:47 | 0 N | 0.0000MPa
4180 | 오후 12:49:47 | 0 N | 0.0000MPa
4179 | 오후 12:49:46 | 0 N | 0.0000MPa
4178 | 오후 12:49:46 | 0 N | 0.0000MPa
4177 | 오후 12:49:46 | 0 N | 0.0000MPa
4176 | 오후 12:49:46 | 0 N | 0.0000MPa
4175 | 오후 12:49:46 | 0 N | 0.0000MPa
4174 | 오후 12:49:45 | 0 N | 0.0000MPa
4173 | 오후 12:49:45 | 0 N | 0.0000MPa
4172 | 오후 12:49:45 | 0 N | 0.0000MPa
4171 | 오후 12:49:45 | 0 N | 0.0000MPa
4170 | 오후 12:49:45 | 0 N | 0.0000MPa
4169 | 오후 12:49:44 | 0 N | 0.0000MPa
4168 | 오후 12:49:44 | 0 N | 0.0000MPa
4167 | 오후 12:49:44 | 0 N | 0.0000MPa
4166 | 오후 12:49:44 | 0 N | 0.0000MPa
4165 | 오후 12:49:44 | 0 N | 0.0000MPa
4164 | 오후 12:49:44 | 0 N | 0.0000MPa
4163 | 오후 12:49:43 | 0 N | 0.0000MPa
4162 | 오후 12:49:43 | 0 N | 0.0000MPa
4161 | 오후 12:49:43 | 0 N | 0.0000MPa
4160 | 오후 12:49:43 | 0 N | 0.0000MPa
4159 | 오후 12:49:43 | 0 N | 0.0000MPa
4158 | 오후 12:49:42 | 0 N | 0.0000MPa
4157 | 오후 12:49:42 | 0 N | 0.0000MPa
4156 | 오후 12:49:42 | 0 N | 0.0000MPa
4155 | 오후 12:49:42 | 0 N | 0.0000MPa
4154 | 오후 12:49:42 | 0 N | 0.0000MPa
4153 | 오후 12:49:41 | 0 N | 0.0000MPa
4152 | 오후 12:49:41 | 0 N | 0.0000MPa
4151 | 오후 12:49:41 | 0 N | 0.0000MPa
4150 | 오후 12:49:41 | 0 N | 0.0000MPa
4149 | 오후 12:49:41 | 0 N | 0.0000MPa
4148 | 오후 12:49:41 | 0 N | 0.0000MPa
4147 | 오후 12:49:40 | 0 N | 0.0000MPa
4146 | 오후 12:49:40 | 0 N | 0.0000MPa
4145 | 오후 12:49:40 | 0 N | 0.0000MPa
4144 | 오후 12:49:40 | 0 N | 0.0000MPa
4143 | 오후 12:49:40 | 0 N | 0.0000MPa
4142 | 오후 12:49:39 | 0 N | 0.0000MPa
4141 | 오후 12:49:39 | 0 N | 0.0000MPa
4140 | 오후 12:49:39 | 0 N | 0.0000MPa
4139 | 오후 12:49:39 | 0 N | 0.0000MPa
4138 | 오후 12:49:39 | 0 N | 0.0000MPa
4137 | 오후 12:49:38 | 0 N | 0.0000MPa
4136 | 오후 12:49:38 | 0 N | 0.0000MPa
4135 | 오후 12:49:38 | 0 N | 0.0000MPa
4134 | 오후 12:49:38 | 0 N | 0.0000MPa
4133 | 오후 12:49:38 | 0 N | 0.0000MPa
4132 | 오후 12:49:38 | 0 N | 0.0000MPa
4131 | 오후 12:49:37 | 0 N | 0.0000MPa
4130 | 오후 12:49:37 | 0 N | 0.0000MPa
4129 | 오후 12:49:37 | 0 N | 0.0000MPa
4128 | 오후 12:49:37 | 0 N | 0.0000MPa
4127 | 오후 12:49:37 | 0 N | 0.0000MPa
4126 | 오후 12:49:36 | 0 N | 0.0000MPa
4125 | 오후 12:49:36 | 0 N | 0.0000MPa
4124 | 오후 12:49:36 | 0 N | 0.0000MPa
4123 | 오후 12:49:36 | 0 N | 0.0000MPa
4122 | 오후 12:49:36 | 0 N | 0.0000MPa
4121 | 오후 12:49:35 | 0 N | 0.0000MPa
4120 | 오후 12:49:35 | 0 N | 0.0000MPa
4119 | 오후 12:49:35 | 0 N | 0.0000MPa
4118 | 오후 12:49:35 | 0 N | 0.0000MPa
4117 | 오후 12:49:35 | 0 N | 0.0000MPa
4116 | 오후 12:49:35 | 0 N | 0.0000MPa
4115 | 오후 12:49:34 | 0 N | 0.0000MPa
4114 | 오후 12:49:34 | 0 N | 0.0000MPa
4113 | 오후 12:49:34 | 0 N | 0.0000MPa
4112 | 오후 12:49:34 | 0 N | 0.0000MPa
4111 | 오후 12:49:34 | 0 N | 0.0000MPa
4110 | 오후 12:49:33 | 0 N | 0.0000MPa
4109 | 오후 12:49:33 | 0 N | 0.0000MPa
4108 | 오후 12:49:33 | 0 N | 0.0000MPa
4107 | 오후 12:49:33 | 0 N | 0.0000MPa
4106 | 오후 12:49:33 | 0 N | 0.0000MPa
4105 | 오후 12:49:32 | 0 N | 0.0000MPa
4104 | 오후 12:49:32 | 0 N | 0.0000MPa
4103 | 오후 12:49:32 | 0 N | 0.0000MPa
4102 | 오후 12:49:32 | 0 N | 0.0000MPa
4101 | 오후 12:49:32 | 0 N | 0.0000MPa
4100 | 오후 12:49:32 | 0 N | 0.0000MPa
4099 | 오후 12:49:31 | 0 N | 0.0000MPa
4098 | 오후 12:49:31 | 0 N | 0.0000MPa
4097 | 오후 12:49:31 | 0 N | 0.0000MPa
4096 | 오후 12:49:31 | 0 N | 0.0000MPa
4095 | 오후 12:49:31 | 0 N | 0.0000MPa
4094 | 오후 12:49:30 | 0 N | 0.0000MPa
4093 | 오후 12:49:30 | 0 N | 0.0000MPa
4092 | 오후 12:49:30 | 0 N | 0.0000MPa
4091 | 오후 12:49:30 | 0 N | 0.0000MPa
4090 | 오후 12:49:30 | 0 N | 0.0000MPa
4089 | 오후 12:49:29 | 0 N | 0.0000MPa
4088 | 오후 12:49:29 | 0 N | 0.0000MPa
4087 | 오후 12:49:29 | 0 N | 0.0000MPa
4086 | 오후 12:49:29 | 0 N | 0.0000MPa
4085 | 오후 12:49:29 | 0 N | 0.0000MPa
4084 | 오후 12:49:29 | 0 N | 0.0000MPa
4083 | 오후 12:49:28 | 0 N | 0.0000MPa
4082 | 오후 12:49:28 | 0 N | 0.0000MPa
4081 | 오후 12:49:28 | 0 N | 0.0000MPa
4080 | 오후 12:49:28 | 0 N | 0.0000MPa
4079 | 오후 12:49:28 | 0 N | 0.0000MPa
4078 | 오후 12:49:27 | 0 N | 0.0000MPa
4077 | 오후 12:49:27 | 0 N | 0.0000MPa
4076 | 오후 12:49:27 | 0 N | 0.0000MPa
4075 | 오후 12:49:27 | 0 N | 0.0000MPa
4074 | 오후 12:49:27 | 0 N | 0.0000MPa
4073 | 오후 12:49:26 | 0 N | 0.0000MPa
4072 | 오후 12:49:26 | 0 N | 0.0000MPa
4071 | 오후 12:49:26 | 0 N | 0.0000MPa
4070 | 오후 12:49:26 | 0 N | 0.0000MPa
4069 | 오후 12:49:26 | 0 N | 0.0000MPa
4068 | 오후 12:49:25 | 0 N | 0.0000MPa
4067 | 오후 12:49:25 | 0 N | 0.0000MPa
4066 | 오후 12:49:25 | 0 N | 0.0000MPa
4065 | 오후 12:49:25 | 0 N | 0.0000MPa
4064 | 오후 12:49:25 | 0 N | 0.0000MPa
4063 | 오후 12:49:25 | 0 N | 0.0000MPa
4062 | 오후 12:49:24 | 0 N | 0.0000MPa
4061 | 오후 12:49:24 | 0 N | 0.0000MPa
4060 | 오후 12:49:24 | 0 N | 0.0000MPa
4059 | 오후 12:49:24 | 0 N | 0.0000MPa
4058 | 오후 12:49:24 | 0 N | 0.0000MPa
4057 | 오후 12:49:23 | 0 N | 0.0000MPa
4056 | 오후 12:49:23 | 0 N | 0.0000MPa
4055 | 오후 12:49:23 | 0 N | 0.0000MPa
4054 | 오후 12:49:23 | 0 N | 0.0000MPa
4053 | 오후 12:49:23 | 0 N | 0.0000MPa
4052 | 오후 12:49:23 | 0 N | 0.0000MPa
4051 | 오후 12:49:22 | 0 N | 0.0000MPa
4050 | 오후 12:49:22 | 0 N | 0.0000MPa
4049 | 오후 12:49:22 | 0 N | 0.0000MPa
4048 | 오후 12:49:22 | 0 N | 0.0000MPa
4047 | 오후 12:49:22 | 0 N | 0.0000MPa
4046 | 오후 12:49:21 | 0 N | 0.0000MPa
4045 | 오후 12:49:21 | 0 N | 0.0000MPa
4044 | 오후 12:49:21 | 0 N | 0.0000MPa
4043 | 오후 12:49:21 | 0 N | 0.0000MPa
4042 | 오후 12:49:21 | 0 N | 0.0000MPa
4041 | 오후 12:49:20 | 0 N | 0.0000MPa
4040 | 오후 12:49:20 | 0 N | 0.0000MPa
4039 | 오후 12:49:20 | 0 N | 0.0000MPa
4038 | 오후 12:49:20 | 0 N | 0.0000MPa
4037 | 오후 12:49:20 | 0 N | 0.0000MPa
4036 | 오후 12:49:19 | 0 N | 0.0000MPa
4035 | 오후 12:49:19 | 0 N | 0.0000MPa
4034 | 오후 12:49:19 | 0 N | 0.0000MPa
4033 | 오후 12:49:19 | 0 N | 0.0000MPa
4032 | 오후 12:49:19 | 0 N | 0.0000MPa
4031 | 오후 12:49:19 | 0 N | 0.0000MPa
4030 | 오후 12:49:18 | 0 N | 0.0000MPa
4029 | 오후 12:49:18 | 0 N | 0.0000MPa
4028 | 오후 12:49:18 | 0 N | 0.0000MPa
4027 | 오후 12:49:18 | 0 N | 0.0000MPa
4026 | 오후 12:49:18 | 0 N | 0.0000MPa
4025 | 오후 12:49:17 | 0 N | 0.0000MPa
4024 | 오후 12:49:17 | 0 N | 0.0000MPa
4023 | 오후 12:49:17 | 0 N | 0.0000MPa
4022 | 오후 12:49:17 | 0 N | 0.0000MPa
4021 | 오후 12:49:17 | 0 N | 0.0000MPa
4020 | 오후 12:49:16 | 0 N | 0.0000MPa
4019 | 오후 12:49:16 | 0 N | 0.0000MPa
4018 | 오후 12:49:16 | 0 N | 0.0000MPa
4017 | 오후 12:49:16 | 0 N | 0.0000MPa
4016 | 오후 12:49:16 | 0 N | 0.0000MPa
4015 | 오후 12:49:16 | 0 N | 0.0000MPa
4014 | 오후 12:49:15 | 0 N | 0.0000MPa
4013 | 오후 12:49:15 | 0 N | 0.0000MPa
4012 | 오후 12:49:15 | 0 N | 0.0000MPa
4011 | 오후 12:49:15 | 0 N | 0.0000MPa
4010 | 오후 12:49:15 | 0 N | 0.0000MPa
4009 | 오후 12:49:14 | 0 N | 0.0000MPa
4008 | 오후 12:49:14 | 0 N | 0.0000MPa
4007 | 오후 12:49:14 | 0 N | 0.0000MPa
4006 | 오후 12:49:14 | 0 N | 0.0000MPa
4005 | 오후 12:49:14 | 0 N | 0.0000MPa
4004 | 오후 12:49:13 | 0 N | 0.0000MPa
4003 | 오후 12:49:13 | 0 N | 0.0000MPa
4002 | 오후 12:49:13 | 0 N | 0.0000MPa
4001 | 오후 12:49:13 | 0 N | 0.0000MPa
4000 | 오후 12:49:13 | 0 N | 0.0000MPa
3999 | 오후 12:49:13 | 0 N | 0.0000MPa
3998 | 오후 12:49:12 | 0 N | 0.0000MPa
3997 | 오후 12:49:12 | 0 N | 0.0000MPa
3996 | 오후 12:49:12 | 0 N | 0.0000MPa
3995 | 오후 12:49:12 | 0 N | 0.0000MPa
3994 | 오후 12:49:12 | 0 N | 0.0000MPa
3993 | 오후 12:49:11 | 0 N | 0.0000MPa
3992 | 오후 12:49:11 | 0 N | 0.0000MPa
3991 | 오후 12:49:11 | 0 N | 0.0000MPa
3990 | 오후 12:49:11 | 0 N | 0.0000MPa
3989 | 오후 12:49:11 | 0 N | 0.0000MPa
3988 | 오후 12:49:10 | 0 N | 0.0000MPa
3987 | 오후 12:49:10 | 0 N | 0.0000MPa
3986 | 오후 12:49:10 | 0 N | 0.0000MPa
3985 | 오후 12:49:10 | 0 N | 0.0000MPa
3984 | 오후 12:49:10 | 0 N | 0.0000MPa
3983 | 오후 12:49:10 | 0 N | 0.0000MPa
3982 | 오후 12:49:09 | 0 N | 0.0000MPa
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

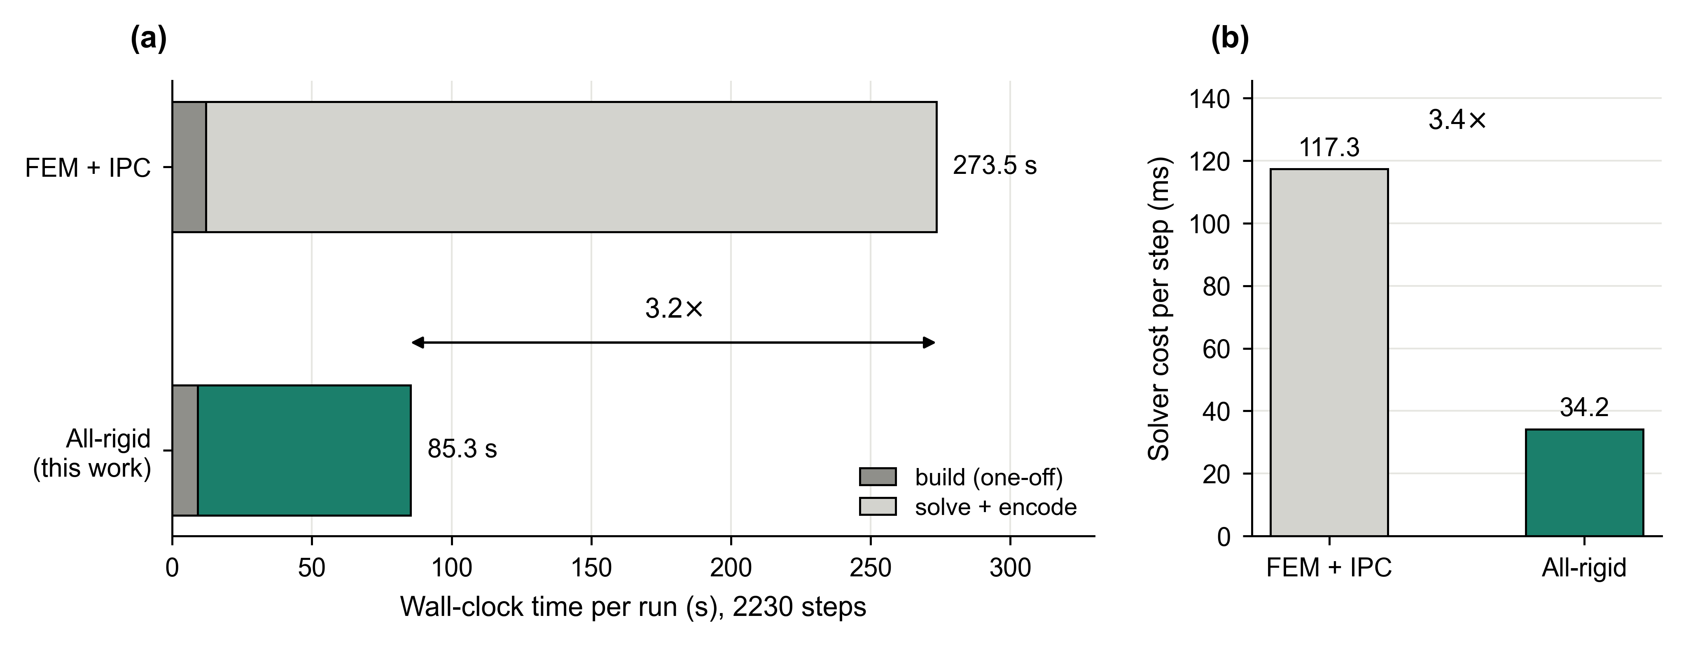
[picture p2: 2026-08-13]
docs/rigid_vs_fem_cost.png

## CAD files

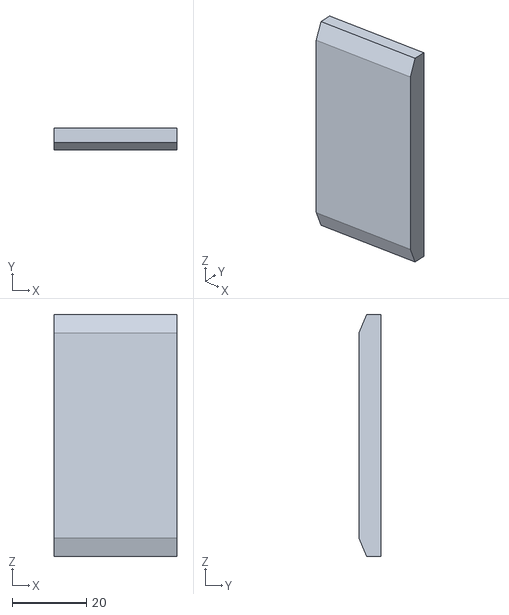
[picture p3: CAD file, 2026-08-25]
Crusher_Genesis/assets/MJCF/L2_Left_Wall_body_hull_002.stl
33.0 x 6.03 x 65.0

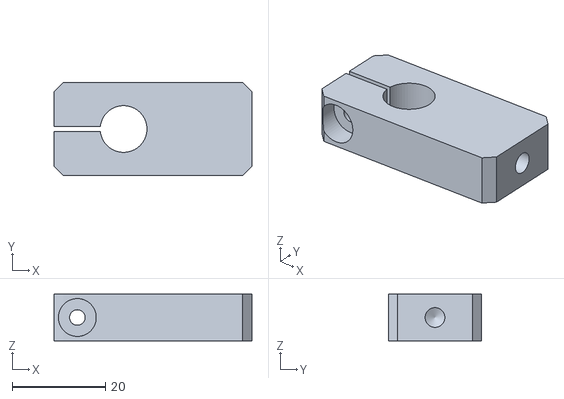
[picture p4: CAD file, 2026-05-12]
Crusher_Genesis/assets/MJCF/meshes/L7_Link3_1.stl
42.4 x 20.0 x 10.0

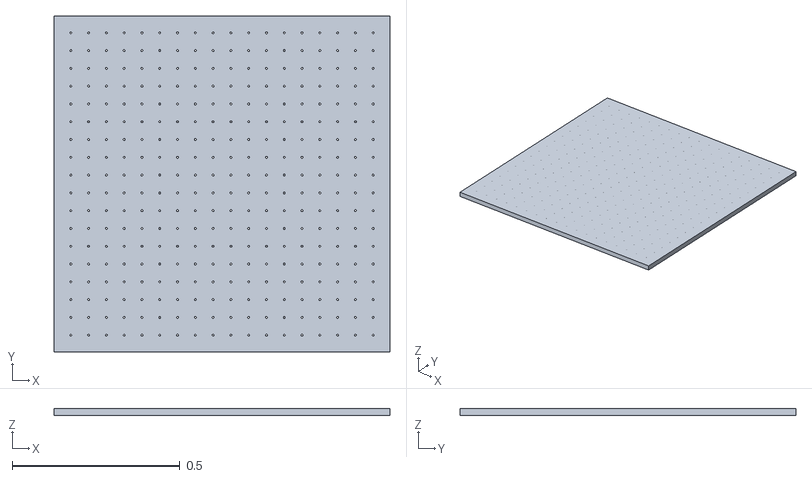
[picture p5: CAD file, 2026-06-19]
Crusher_Genesis/assets/robots/assets/aluminum_plate.stl
1.00 x 1.00 x 0.02

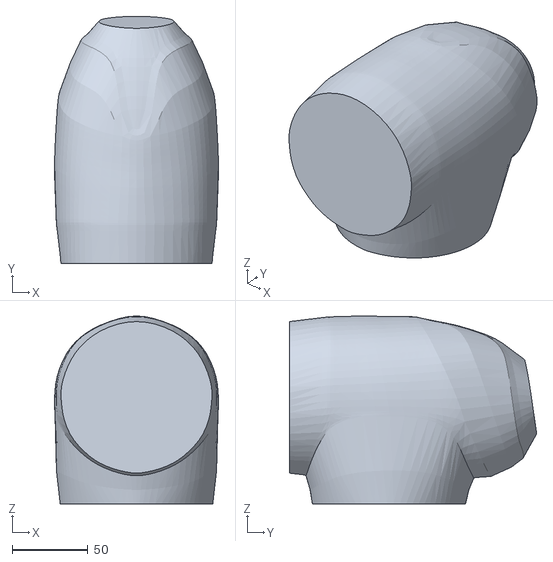
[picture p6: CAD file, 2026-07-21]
Crusher_Genesis/assets/robots/m0609/assets/MF0609_4_1_ss.obj
108.0 x 163.0 x 123.8

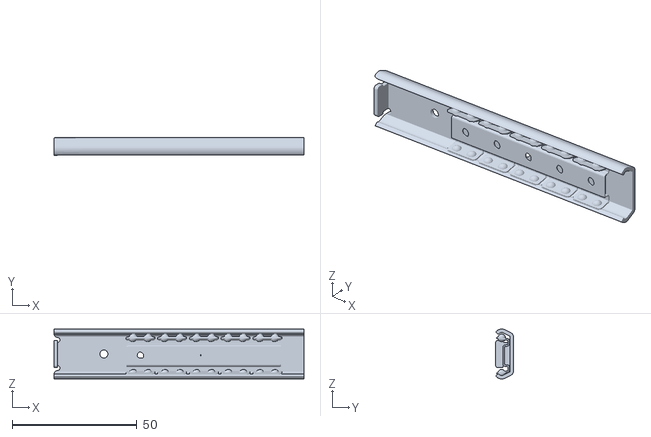
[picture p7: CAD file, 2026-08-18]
Crusher_Genesis/assets/robots/recovery2_mjcf/meshes/RightSlider1_1_ss.obj
100.1 x 7.10 x 20.0

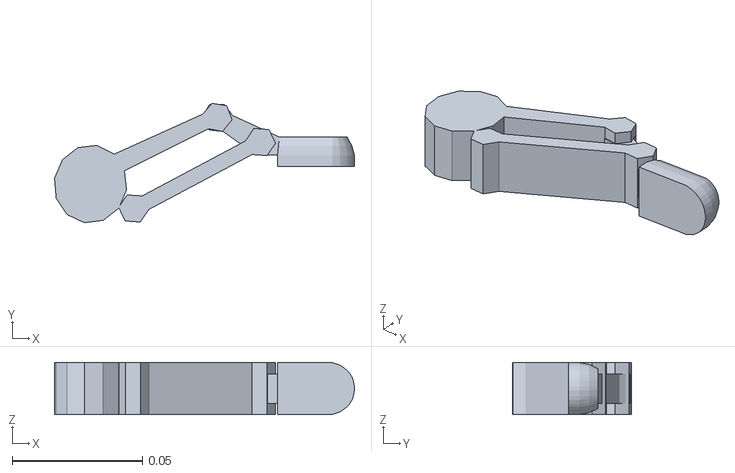
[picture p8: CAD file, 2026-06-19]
Crusher_Genesis/assets/robots/rg2/assets/finger_neutral.stl
0.115 x 0.0458 x 0.02

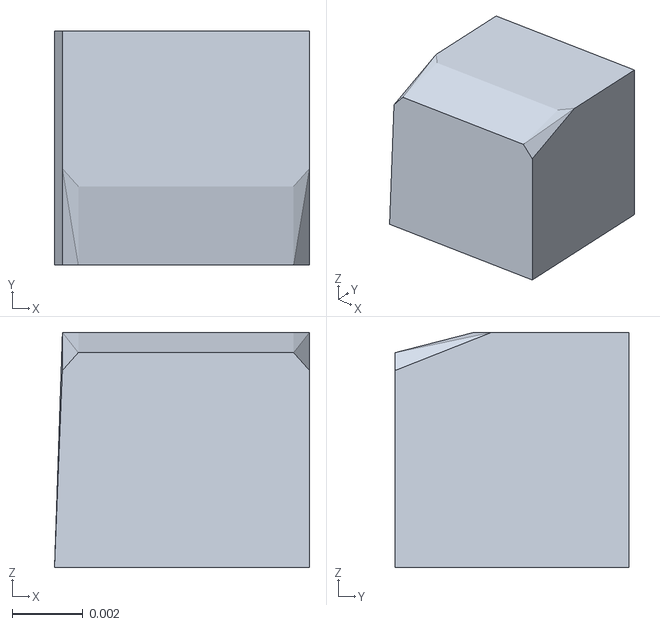
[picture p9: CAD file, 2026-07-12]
Crusher_Genesis/assets/robots/rg2/reference_onrobot_ros/meshes/rg2_v1/coacd/finger_tip_hull_004.stl
0.00722 x 0.00662 x 0.00666

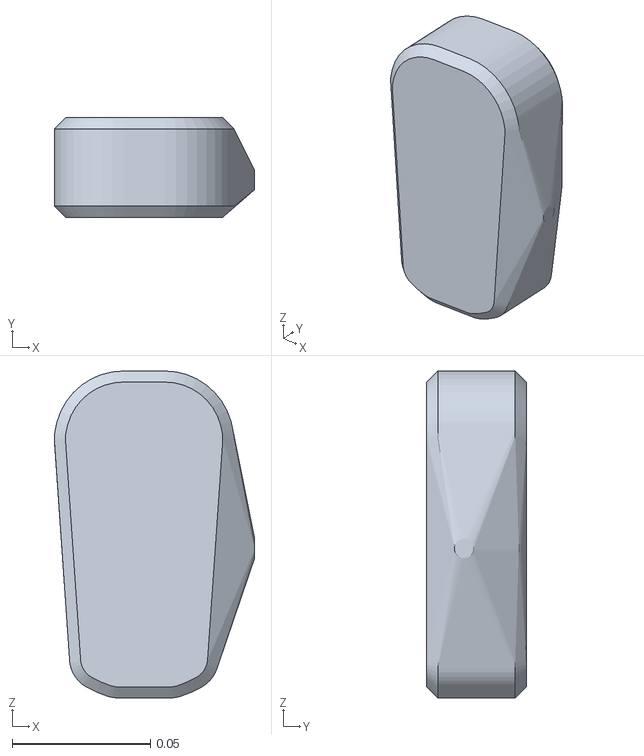
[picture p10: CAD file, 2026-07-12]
Crusher_Genesis/assets/robots/rg2/reference_onrobot_ros/meshes/rg2_v1/collision/body.stl
0.0725 x 0.036 x 0.118

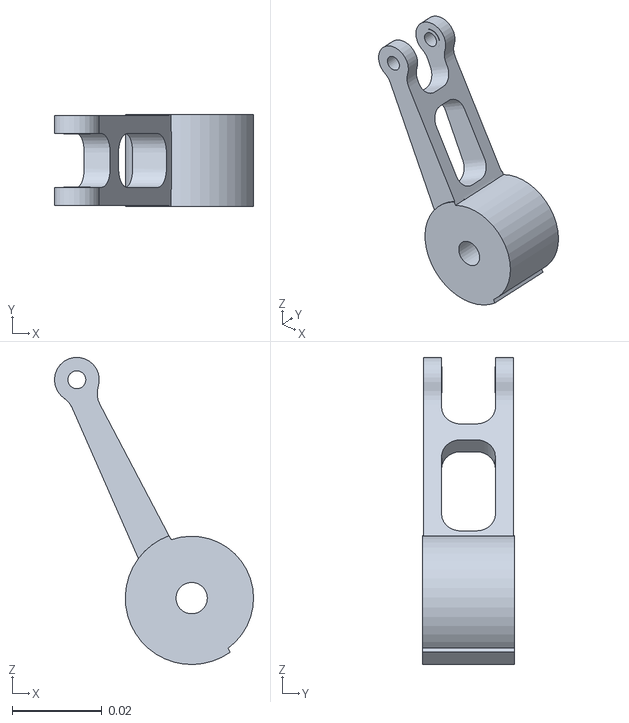
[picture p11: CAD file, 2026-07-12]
Crusher_Genesis/assets/robots/rg2/reference_onrobot_ros/meshes/rg2_v1/visual/moment_arm.stl
0.0444 x 0.0206 x 0.0684

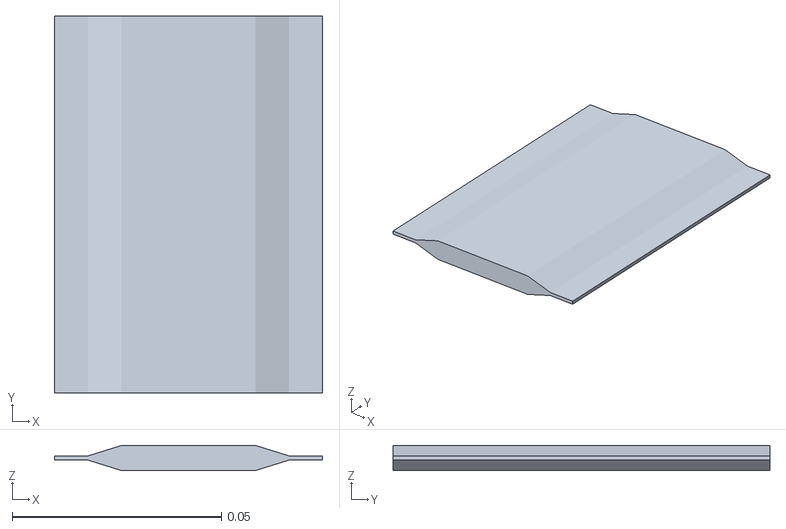
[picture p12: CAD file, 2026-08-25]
Crusher_Genesis/assets/robots/Samplebag/Samplebag_seal_pouch3_sealslab1mm.stl
0.064 x 0.09 x 0.006

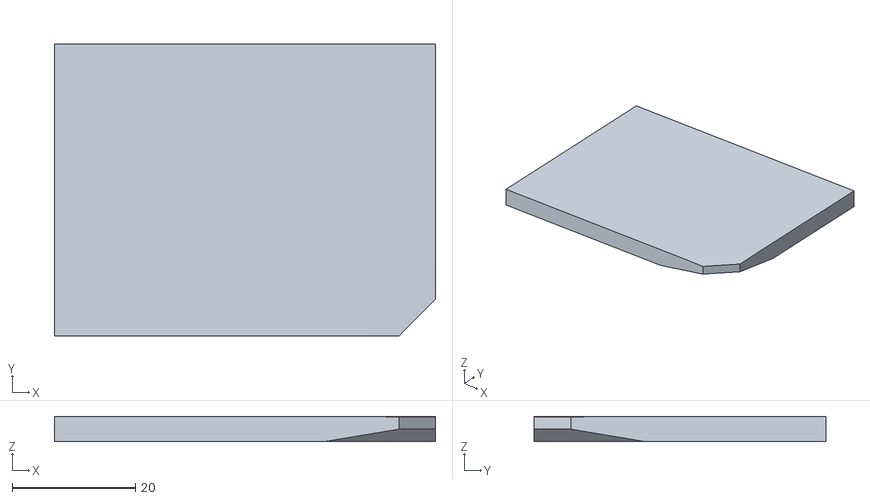
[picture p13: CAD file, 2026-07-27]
Crusher_Genesis/assets/robots/고정장치_description/meshes/T1_1_hull_008.stl
61.9 x 47.5 x 4.07

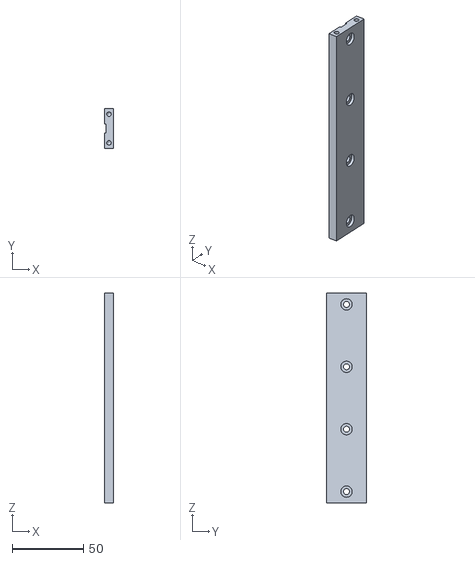
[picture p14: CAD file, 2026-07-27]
Crusher_Genesis/assets/robots/석션V1_description/meshes/Hbeam_L_1_ss.obj
6.00 x 28.0 x 147.0

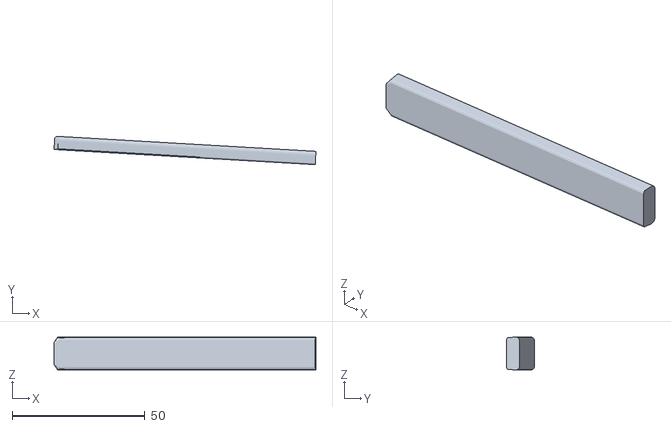
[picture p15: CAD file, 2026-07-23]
Crusher_Genesis/assets/robots/회수장치2_description/meshes/LeftSlider2_1_hull.stl
98.9 x 10.7 x 12.4

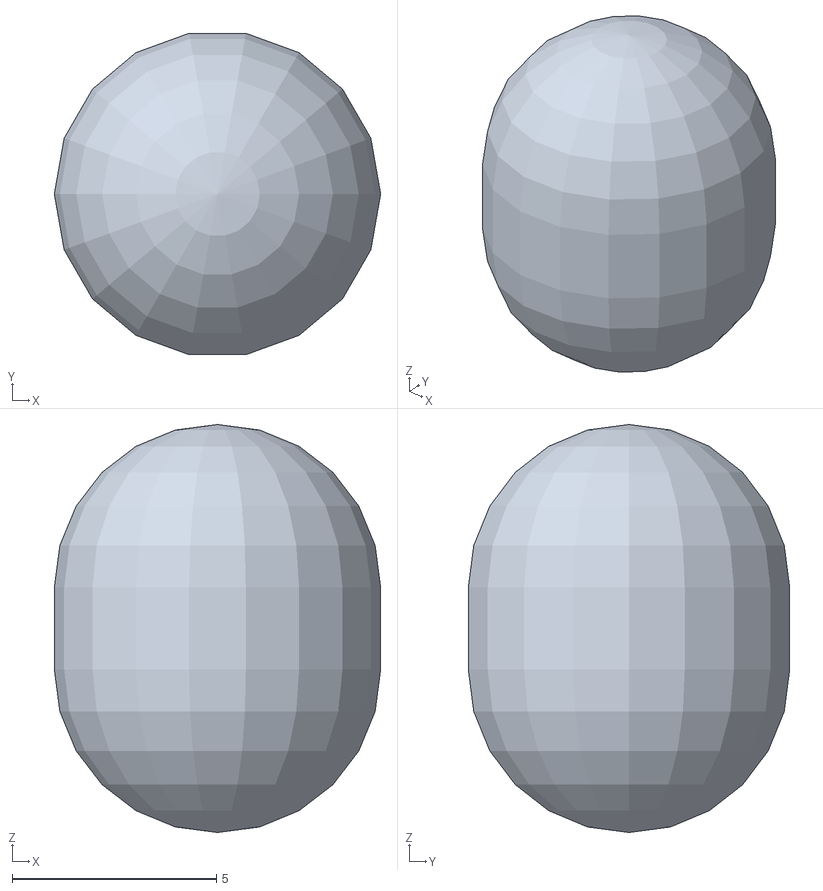
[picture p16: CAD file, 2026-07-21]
Crusher_Genesis/FEM/Result/_capsule_surface_for_mujoco.stl
8.00 x 7.88 x 10.0

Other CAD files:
Crusher_Genesis/Crusher_M0609_RG2_Tablet_Samplebag/RESULT/_bag_seal_uv.obj
Crusher_Genesis/fusion_addin/fusion2urdf/Example/Basic_Robot_description/meshes/left_wheel_1.stl
Crusher_Genesis/Recovery2_only/RESULT/_analytic_capsule_recovery2_drop.stl
Crusher_Genesis/Sim_result/crusher_samplebag_open.stl
Crusher_Genesis/Crusher_M0609_RG2_Tablet_Samplebag/RESULT/_analytic_capsule_v2.stl
Crusher_Genesis/Crusher_M0609_RG2_Tablet_Samplebag/RESULT/_bag_seal_colored.ply
Crusher_Genesis/Legacy_vs_IPC/RESULT/_bag_pbd_proxy.stl
Crusher_Genesis/Legacy_vs_IPC/RESULT/_bag_seal_uv.obj
Crusher_Genesis/Legacy_vs_IPC/RESULT/_tablet_rigid_capsule.stl
Crusher_Genesis/Sim_result/Samplebag_v2.stl
Crusher_Genesis/Sim_result/_ipc_test_bag.stl
Crusher_Genesis/Sim_result/_tablet_decimated_1000.stl
Crusher_Genesis/Sim_result/_tablet_decimated_200.stl
Crusher_Genesis/Sim_result/_tablet_decimated_50.stl
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

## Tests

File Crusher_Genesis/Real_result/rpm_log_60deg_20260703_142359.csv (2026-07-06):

elapsed_s | rpm | state | crank_deg
0.4912686347961426 | 1282 | STRIKE | 0.0
0.5414652824401855 | 1282 | STRIKE | 17.824709145527965
0.5996794700622559 | 1282 | STRIKE | 19.645995059103335
0.6498122215270996 | 1282 | STRIKE | 21.75818152697581
0.6999068260192871 | 1282 | STRIKE | 23.577149094275708
0.7500166893005371 | 1282 | STRIKE | 25.394732574246962
0.8001213073730469 | 1282 | STRIKE | 27.212869689149674
0.850165605545044 | 392 | STRIKE | 29.030816492044696
0.8993520736694336 | 392 | STRIKE | 29.58602493214157
0.9486429691314697 | 392 | STRIKE | 30.131716314351777
0.9988150596618652 | 392 | STRIKE | 30.678566248911725
1.0491724014282227 | 392 | STRIKE | 31.235192460833847
1.0982422828674316 | 392 | STRIKE | 31.793873912883246
1.1472926139831543 | 392 | STRIKE | 32.33827184281258
1.1963369846343994 | 1733 | STRIKE | 32.88245287481343
1.2464430332183838 | 1733 | STRIKE | 35.287940450434405
1.29659104347229 | 1733 | STRIKE | 37.74550032390737
1.346867322921753 | 1733 | STRIKE | 40.205118298530564
1.3960163593292236 | 1733 | STRIKE | 42.671027514169786
1.4452311992645264 | 1733 | STRIKE | 45.08164864890979
1.4956245422363281 | 1733 | STRIKE | 47.495497260453554
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

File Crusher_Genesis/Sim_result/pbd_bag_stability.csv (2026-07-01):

t_s | n_nan | disp_mean_mm | disp_max_mm | vel_mean | vel_max | fix_drift_mm
0.0250 | 0 | 1.41882 | 3.38970 | 0.05675 | 0.13559 | 0.00000
0.0500 | 0 | 1.50875 | 3.45643 | 0.00960 | 0.05442 | 0.00000
0.0750 | 0 | 1.45346 | 3.35183 | 0.00526 | 0.03094 | 0.00000
0.1000 | 0 | 1.38248 | 3.32981 | 0.00514 | 0.02419 | 0.00000
0.1250 | 0 | 1.38346 | 3.33246 | 0.00186 | 0.01483 | 0.00000
0.1500 | 0 | 1.42652 | 3.31561 | 0.00300 | 0.01317 | 0.00000
0.1750 | 0 | 1.44378 | 3.33948 | 0.00192 | 0.00715 | 0.00000
0.2000 | 0 | 1.41859 | 3.31809 | 0.00255 | 0.00721 | 0.00000
0.2250 | 0 | 1.40103 | 3.31515 | 0.00189 | 0.01045 | 0.00000
0.2500 | 0 | 1.41174 | 3.30203 | 0.00111 | 0.00512 | 0.00000
0.2750 | 0 | 1.42608 | 3.31275 | 0.00075 | 0.00338 | 0.00000
0.3000 | 0 | 1.42143 | 3.32266 | 0.00097 | 0.00264 | 0.00000
0.3250 | 0 | 1.41289 | 3.32527 | 0.00119 | 0.00429 | 0.00000
0.3500 | 0 | 1.41517 | 3.33365 | 0.00088 | 0.00273 | 0.00000
0.3750 | 0 | 1.42047 | 3.32443 | 0.00061 | 0.00337 | 0.00000
0.4000 | 0 | 1.41911 | 3.32014 | 0.00015 | 0.00087 | 0.00000
0.4250 | 0 | 1.41587 | 3.32496 | 0.00046 | 0.00279 | 0.00000
0.4500 | 0 | 1.41641 | 3.32463 | 0.00053 | 0.00182 | 0.00000
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

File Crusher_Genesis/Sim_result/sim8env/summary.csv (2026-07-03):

theta_deg | contact_deg | mean_peak_N | n_strikes
15 | 15 | 0.0 | 0
30 | 30.413467656793713 | 841.1453294117727 | 25
45 | 46.137816260184906 | 612.7632082473111 | 25
60 | 60.65159119008415 | 536.6339549006128 | 25
75 | 75.33044507110445 | 510.9611981646042 | 25
90 | 90.20076939380657 | 524.6082550460173 | 25
105 | 105.20655171091398 | 570.9553264349394 | 25
120 | 120.06796014213991 | 665.1709958645126 | 25

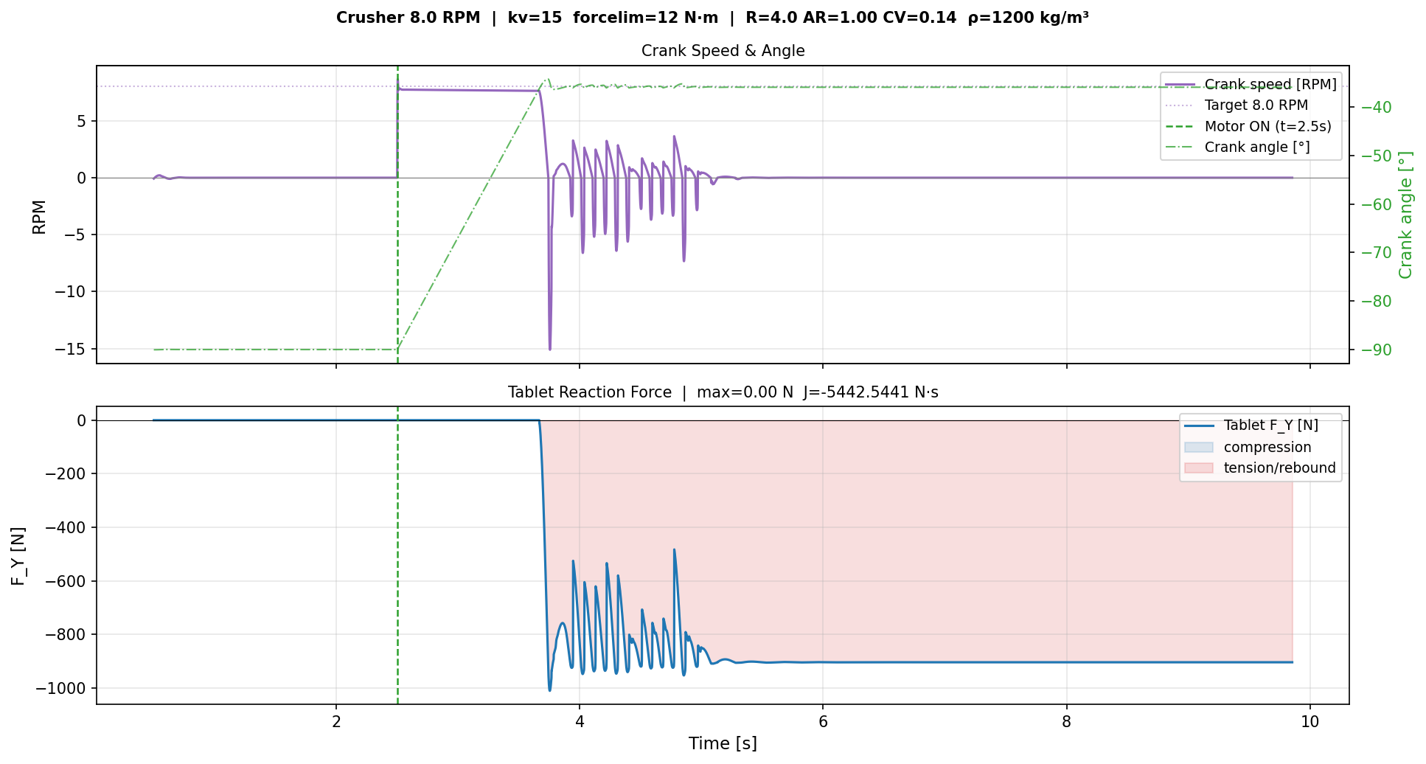
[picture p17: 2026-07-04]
MuJoCo_PlayGround/Sim_result/plot/velctrl_view_tablet_R4.0_AR1.00_CV0.14__20260611_032456__result.png

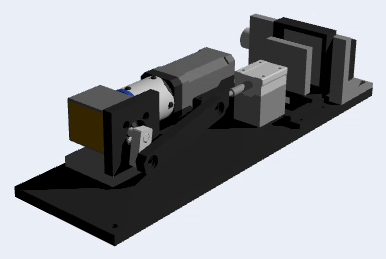
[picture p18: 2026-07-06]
Crusher_Genesis/Sim_result/crusher_frames/cropped/crusher_only_12.png

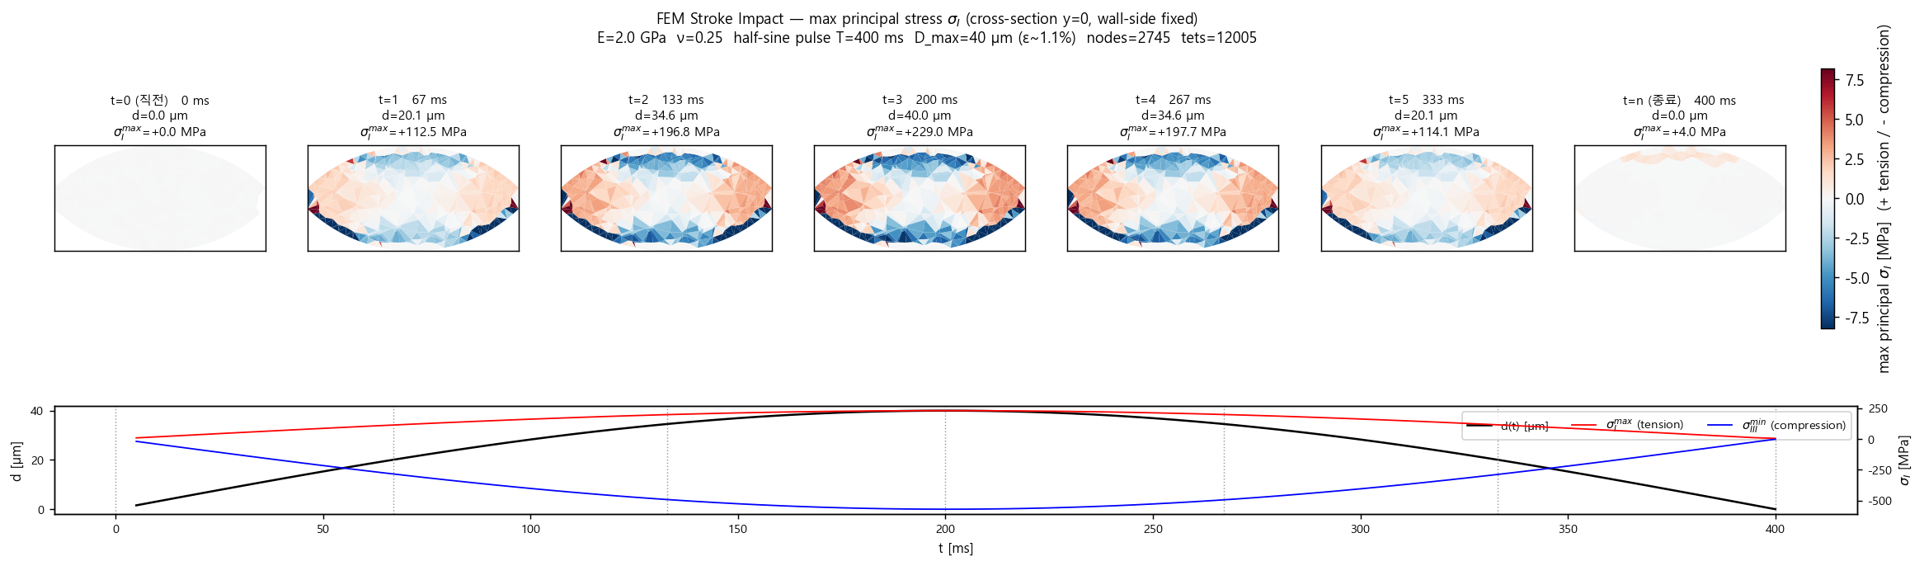
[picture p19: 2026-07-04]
Crusher_Genesis/Sim_result/fem_stroke_impact_20260704_075338_sigI.png

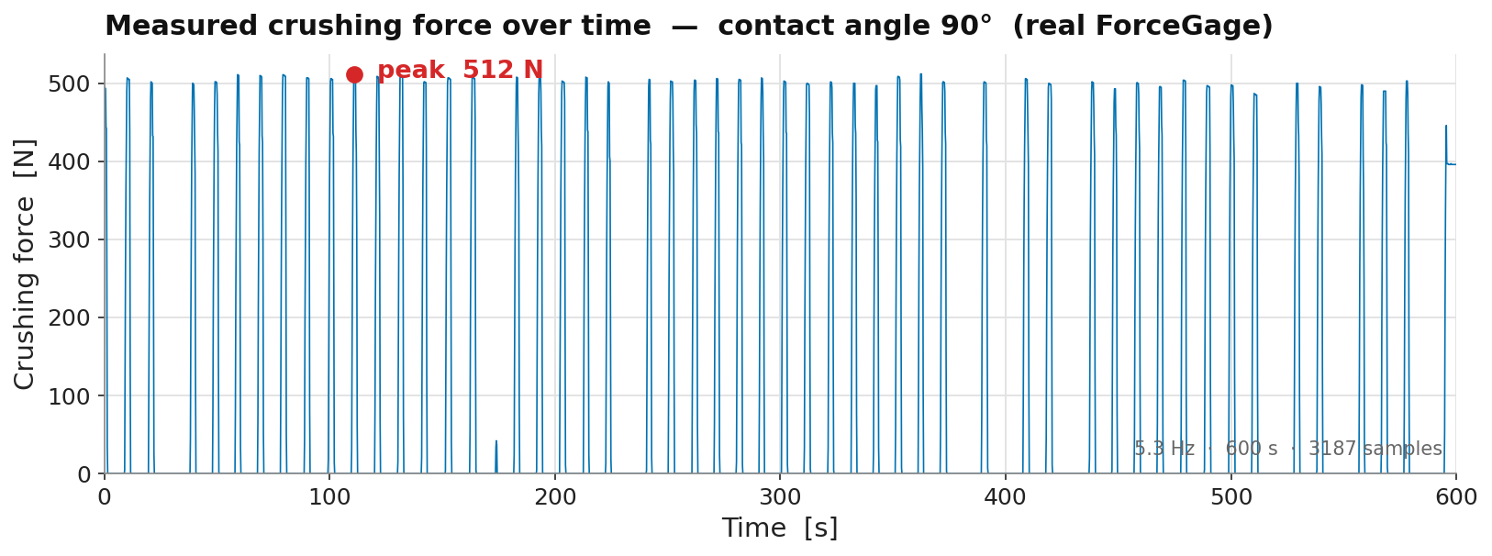
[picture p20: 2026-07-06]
Crusher_Genesis/Real_result/plots/90deg_reaction_profile.png

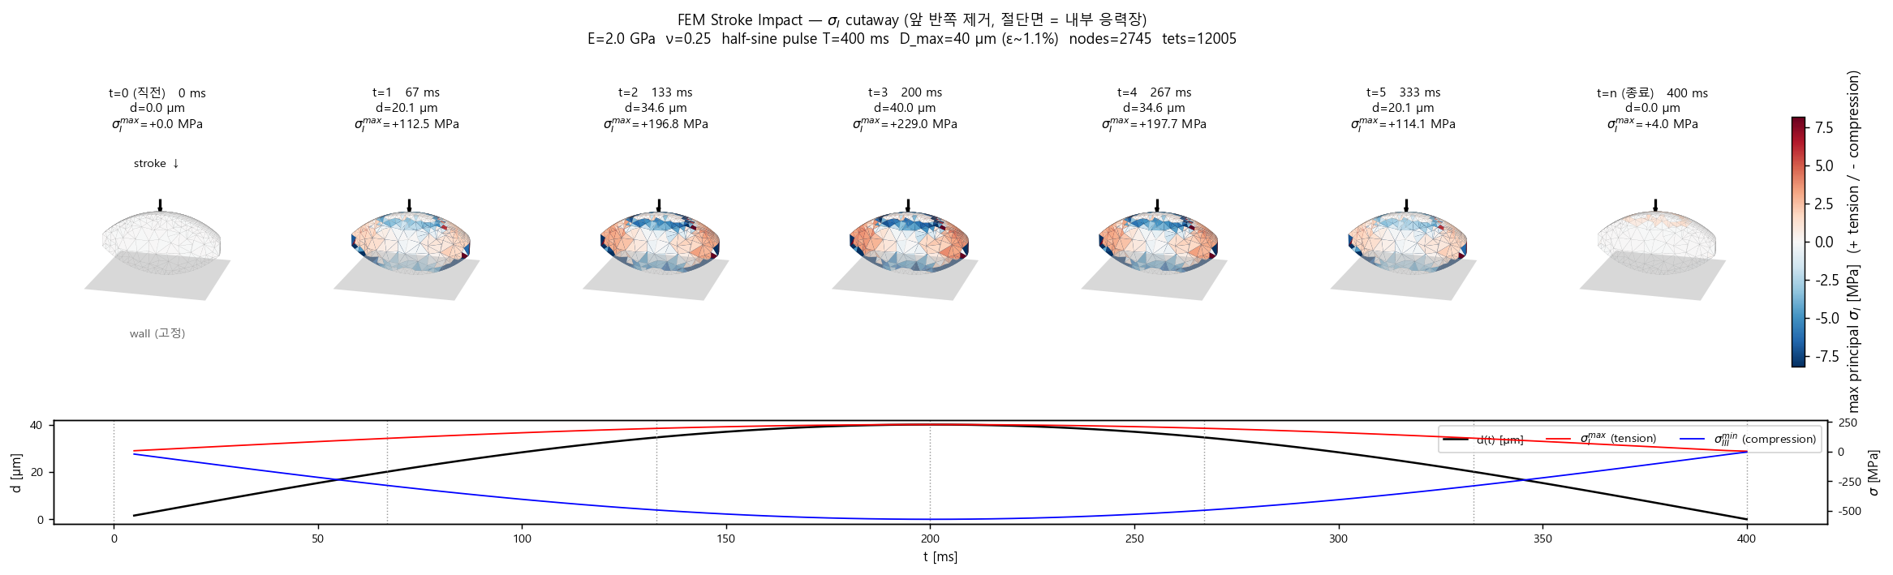
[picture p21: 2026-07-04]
Crusher_Genesis/Sim_result/fem_stroke_impact_20260704_075502_sigI_cut.png

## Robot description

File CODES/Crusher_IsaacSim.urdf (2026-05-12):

<?xml version='1.0' encoding='utf-8'?>
<robot name="Crusher_IsaacSim">
  <link name="base_link">
    <inertial>
      <origin xyz="0.20081918303463628 0.004440188593902392 -0.05971500825180853" rpy="0 0 0" />
      <mass value="3.74185880752948" />
      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
    </inertial>
    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
  </link>
  <link name="1_Slider_jig_1">
    <inertial>
      <origin xyz="0.021499756294432126 0.015732401797129904 -3.3514538629042523e-07" rpy="0 0 0" />
      <mass value="0.33616222476948276" />
      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
    </inertial>
    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
  </link>
  <link name="1_Braket1_1">
    <inertial>
      <origin xyz="0.024999756294432185 0.005000225229731026 0.02488030965737975" rpy="0 0 0" />
      <mass value="0.2750349331083618" />
      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
    </inertial>
    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
  </link>
  <link name="1_Wall1_1">
    <inertial>
      <origin xyz="0.03169585773645228 0.0025070567427059563 0.0016473990107933045" rpy="0 0 0" />
      <mass value="0.16030483412436242" />
      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
    </inertial>
    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
  </link>
  <link name="1_Guide2_1">
    <inertial>
      <origin xyz="5.479363171156937e-05 0.004138425955964932 0.010084722716027603" rpy="0 0 0" />
      <mass value="0.052721698147916954" />
      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
    </inertial>
    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
  </link>
  <link name="1_Guide1_1">
    <inertial>
      <origin xyz="-2.4370557250019687e-07 0.004142946506212735 -0.01009804529300588" rpy="0 0 0" />
      <mass value="0.05257661505376253" />
      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
    </inertial>
    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
  </link>
  <link name="2_Braket2_1">
    <inertial>
      <origin xyz="0.02499975629422685 0.030336408162163427 -6.947282812774097e-05" rpy="0 0 0" />
      <mass value="0.23246246095078596" />
      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
    </inertial>
    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
  </link>
  <link name="3_Bevel_GearBox_1">
    <inertial>
      <origin xyz="0.015447630707306106 -0.012369535386957953 -0.028191361020842548" rpy="0 0 0" />
      <mass value="0.6295222426150034" />
      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
    </inertial>
    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
  </link>
  <link name="4_Bevel_GearBox2_1">
    <inertial>
      <origin xyz="4.975629443217111e-05 2.2522973103233923e-07 -3.3514538626266965e-07" rpy="0 0 0" />
      <mass value="0.0015213299999999668" />
      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
    </inertial>
    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
  </link>
  <link name="4_Motor1_RearBearing_1">
    <inertial>
      <origin xyz="-2.437058176513185e-07 2.2522973099764476e-07 0.002699664854613912" rpy="0 0 0" />
      <mass value="0.010236521913901037" />
      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
    </inertial>
    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
  </link>
  <link name="5_Motor1_RearSnapring_1">
    <inertial>
      <origin xyz="-2.4370556786501574e-07 0.0005864971330963517 -0.00040033514538626025" rpy="0 0 0" />
      <mass value="0.0002520100828965103" />
      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
    </inertial>
    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
  </link>
  <link name="4_Motor1_FrontBearing_1">
    <inertial>
      <origin xyz="-2.437053179538129e-07 2.2522973098376697e-07 -0.003000335145386168" rpy="0 0 0" />
      <mass value="0.010236521913901024" />
      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
    </inertial>
    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
  </link>
  <link name="5_Motor1_FrontSnapring_1">
    <inertial>
      <origin xyz="-2.4370556775399344e-07 0.0005864971330963031 0.0003996648546136933" rpy="0 0 0" />
      <mass value="0.00025201008289651007" />
      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
    </inertial>
    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
  </link>
  <link name="4_Shaft_1">
    <inertial>
      <origin xyz="-3.1205952042964724e-05 2.0270969616764667e-07 -0.022816202807732847" rpy="0 0 0" />
      <mass value="0.032156006738375494" />
      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
    </inertial>
    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
  </link>
  <link name="5_Key_1">
    <inertial>
      <origin xyz="0.0014997562944321502 2.2522973104621702e-07 0.0034996648546137543" rpy="0 0 0" />
      <mass value="0.0006610151407320853" />
      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
    </inertial>
    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
  </link>
  <link name="5_Link1_1">
    <inertial>
      <origin xyz="0.010562809406086393 2.2620055527972083e-07 -0.0050830444725804905" rpy="0 0 0" />
      <mass value="0.03339512428326125" />
      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
    </inertial>
    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
  </link>
  <link name="6_Link2_1">
    <inertial>
      <origin xyz="0.04699975629433255 -3.7650282687790027e-06 0.004922946094953522" rpy="0 0 0" />
      <mass value="0.1631944777407734" />
      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
    </inertial>
    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
  </link>
  <link name="7_Link3_1">
    <inertial>
      <origin xyz="0.007663998665906224 0.00021254504364840582 -0.005000335145374346" rpy="0 0 0" />
      <mass value="0.05460287113526952" />
      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
    </inertial>
    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
  </link>
  <link name="8_Link3_Shaft_1">
    <inertial>
      <origin xyz="0.04565799892472036 2.2522973101846144e-07 -3.3514540309642626e-07" rpy="0 0 0" />
      <mass value="0.005039873731856857" />
      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
    </inertial>
    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
  </link>
  <link name="9_PLATE_v3_1">
    <inertial>
      <origin xyz="0.004970457801119266 2.2522969379129565e-07 -3.3514538626960855e-07" rpy="0 0 0" />
      <mass value="0.1923272981336843" />
      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
    </inertial>
    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
  </link>
  <link name="2_Linear_bush_1">
    <inertial>
      <origin xyz="0.013999756294416188 0.008248758525941022 -0.01200033514538626" rpy="0 0 0" />
      <mass value="0.023802667939284698" />
      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
    </inertial>
    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
  </link>
  <link name="2_Wall3_1">
    <inertial>
      <origin xyz="0.005018170003944722 0.033402092716836765 -0.06032269365452009" rpy="0 0 0" />
      <mass value="0.6090784198626383" />
      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
    </inertial>
    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
  </link>
  <link name="2_GearCase2_1">
    <inertial>
      <origin xyz="9.677530673257717e-05 0.02132232200482271 -0.00498578801431793" rpy="0 0 0" />
      <mass value="0.16020423263853414" />
      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
    </inertial>
    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
  </link>
  <link name="2_GearCase3_1">
    <inertial>
      <origin xyz="9.677248129108529e-05 0.021322322017791037 0.0049851177251886356" rpy="0 0 0" />
      <mass value="0.1602042507838881" />
      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
    </inertial>
    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
  </link>
  <link name="2__Motor2_Braket_1">
    <inertial>
      <origin xyz="-0.010499738996915087 0.010838887123205632 -0.011063774316671743" rpy="0 0 0" />
      <mass value="0.0326038813418568" />
      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
    </inertial>
    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
  </link>
  <link name="3_Motor2_1">
    <inertial>
      <origin xyz="4.972666821090321e-07 1.757601170992995e-07 -0.02490380169772577" rpy="0 0 0" />
      <mass value="0.15833007752880432" />
      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
    </inertial>
    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
  </link>
  <link name="4_Motor2_Shaft_1">
    <inertial>
      <origin xyz="4.970425087247321e-05 2.2522973092131693e-07 0.005999664854613743" rpy="0 0 0" />
      <mass value="0.0011529475977531312" />
      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
    </inertial>
    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
  </link>
  <link name="5_Coupler_1">
    <inertial>
      <origin xyz="3.824259622253745e-06 2.2522973056743334e-07 0.011816502014127733" rpy="0 0 0" />
      <mass value="0.011266786432847734" />
      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
    </inertial>
    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
  </link>
  <link name="6_DcutShaft_1">
    <inertial>
      <origin xyz="0.0002565705212548286 2.2522973724958817e-07 0.020110346368580584" rpy="0 0 0" />
      <mass value="0.016522872684931453" />
      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
    </inertial>
    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
  </link>
  <link name="7_Holder_Bearing2_1">
    <inertial>
      <origin xyz="2.610031956673531e-07 2.252297277641202e-07 0.0014996648546137456" rpy="0 0 0" />
      <mass value="0.001130805775471964" />
      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
    </inertial>
    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
  </link>
  <link name="7_Holder_Bearing1_1">
    <inertial>
      <origin xyz="2.6100321026678586e-07 2.252297417668081e-07 -0.001500335145386271" rpy="0 0 0" />
      <mass value="0.001130805775471964" />
      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
    </inertial>
    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
  </link>
  <link name="2_Left_Wall1_1">
    <inertial>
      <origin xyz="0.020430178983223413 0.017212726817165173 -0.029554874433021815" rpy="0 0 0" />
      <mass value="0.2992365816923497" />
      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
    </inertial>
    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
  </link>
  <link name="4_Reducer1_1">
    <inertial>
      <origin xyz="0.0024997562944320956 7.632783294297951e-17 8.326672684688674e-17" rpy="0 0 0" />
      <mass value="0.05437861263914883" />
      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
    </inertial>
    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
  </link>
  <link name="5_Reducer2_1">
    <inertial>
      <origin xyz="0.021312374976131046 -1.0313176109638666e-07 3.6817771054131754e-14" rpy="0 0 0" />
      <mass value="0.4577821909878664" />
      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
    </inertial>
    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
  </link>
  <link name="6_Motor1_Bolt_1">
    <inertial>
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

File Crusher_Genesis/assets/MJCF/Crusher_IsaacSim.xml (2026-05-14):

<mujoco model="Crusher_IsaacSim">
  <compiler angle="radian"/>

  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

  <worldbody>
    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
    <body name="L4_Shaft_1" pos="-0.062002 0.085278 0.049431" quat="0.5 0.5 0.5 0.5">
      <inertial pos="0.0147839 2.14782e-07 -0.0135426" quat="0.672419 0.218752 0.218752 0.672419" mass="0.0662121" diaginertia="4.16635e-05 3.15958e-05 1.40677e-05"/>
      <joint name="L3_Bevel_GearBox_1_L4_Shaft_1" pos="0 0 0" axis="0 0 1"/>
      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
      <body name="L6_Link2_1" pos="0.02 0 0.0187">
        <inertial pos="0.0469998 -3.76503e-06 0.00492295" quat="0 0.707107 0 0.707107" mass="0.163194" diaginertia="0.000161 0.000157 7e-06"/>
        <joint name="L5_Link1_1_L6_Link2_1" pos="0 0 0" axis="0 0 -1"/>
        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
        <body name="L7_Link3_1" pos="0.094 0 0">
          <inertial pos="0.0958464 0.00976448 -0.00113427" quat="-0.0108928 0.696338 -0.0436585 0.716302" mass="0.287024" diaginertia="0.000924522 0.000888847 0.000127107"/>
          <joint name="L6_Link2_1_L7_Link3_1" pos="0 0 0" axis="0 0 -1"/>
          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
        </body>
      </body>
    </body>
    <body name="L4_Motor2_Shaft_1" pos="-0.099802 0.372198 0.038633" quat="0.5 0.5 0.5 0.5">
      <inertial pos="3.76623e-05 -0.0367559 0.0148282" quat="0.470205 0.882544 0.00325175 -0.00342723" mass="0.115828" diaginertia="9.32374e-05 8.85576e-05 1.96795e-05"/>
      <joint name="L3_Motor2_1_L4_Motor2_Shaft_1" pos="0 0 0" axis="0 0 1" actuatorfrcrange="-100 100"/>
      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
      <body name="L7_Holder_Bearing2_1" pos="0 0 0.067">
        <inertial pos="2.61003e-07 2.2523e-07 0.00149966" mass="0.00113081" diaginertia="1e-06 1e-06 1e-06"/>
        <joint name="L6_DcutShaft_1_L7_Holder_Bearing2_1" pos="0 0 0" axis="0 0 1"/>
        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
      </body>
      <body name="L7_Holder_Bearing1_1" pos="0 0 0.049">
        <inertial pos="2.61003e-07 2.2523e-07 -0.00150034" mass="0.00113081" diaginertia="1e-06 1e-06 1e-06"/>
        <joint name="L6_DcutShaft_1_L7_Holder_Bearing1_1" pos="0 0 0" axis="0 0 -1"/>
        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
      </body>
    </body>
    <body name="L2_Left_Wall1_1" pos="-0.017802 0.286278 0.016542" quat="0.5 0.5 0.5 0.5">
      <inertial pos="0.0210989 0.0165544 -0.0284615" quat="0.732108 0.680689 0.0237381 -0.0108493" mass="0.312402" diaginertia="0.000368114 0.000265256 0.000193111"/>
      <joint name="L1_Guide1_1_L2_Left_Wall1_1" pos="0 0 0" axis="-1 0 0" type="slide" actuatorfrcrange="-100 100"/>
      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
    </body>
  </worldbody>
</mujoco>

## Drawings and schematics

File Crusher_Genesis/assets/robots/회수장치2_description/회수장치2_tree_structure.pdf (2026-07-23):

# 회수장치2 -- 현재 트리(tree) 구조 중복 Crank_1 제거 + 전 joint ParentLink_ChildLink 명명 완료, closed-loop 없음

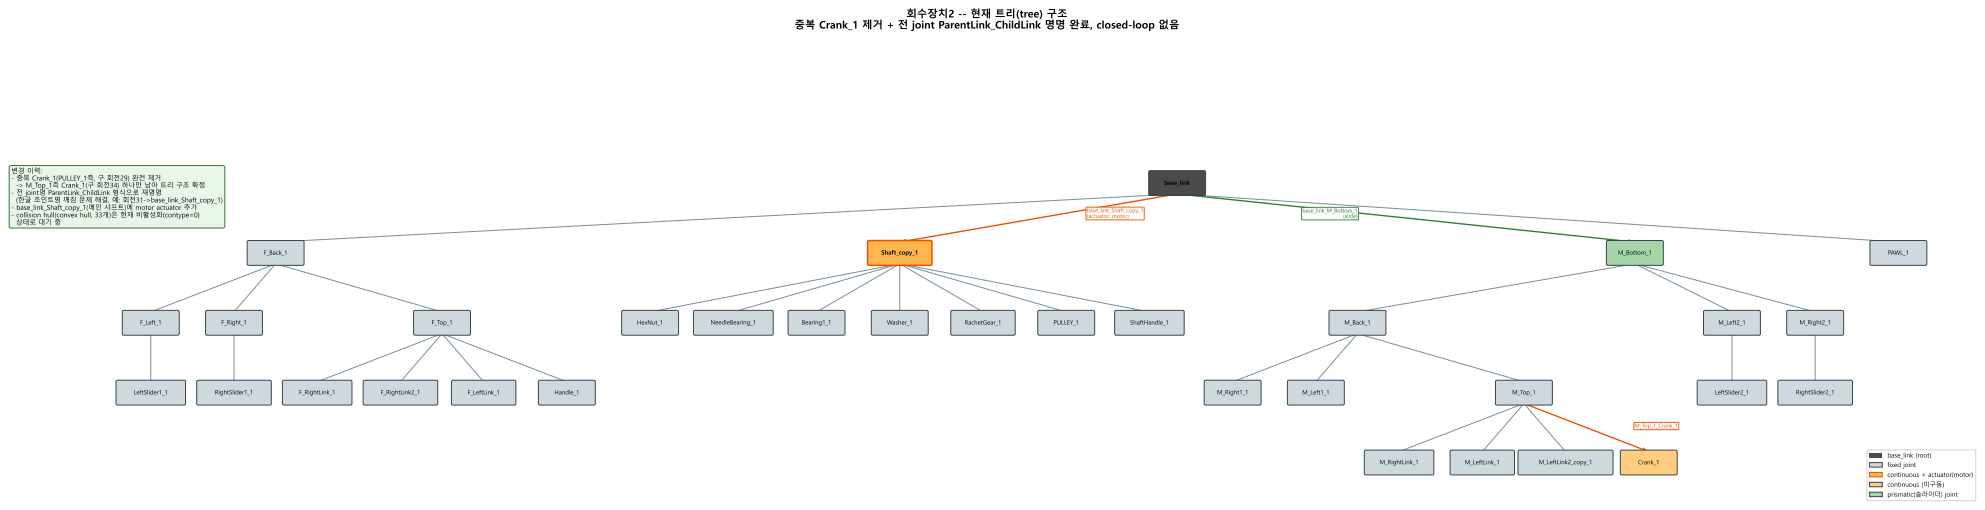
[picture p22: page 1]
LeftSlider1_1; F_Left_1; RightSlider1_1; F_Right_1; F_RightLink_1; F_RightLink2_1; F_LeftLink_1; Handle_1; F_Top_1; F_Back_1; HexNut_1; NeedleBearing_1; Bearing1_1; Washer_1; RachetGear_1; PULLEY_1; ShaftHandle_1; Shaft_copy_1; M_Right1_1; M_Left1_1; M_RightLink_1; M_LeftLink_1; M_LeftLink2_copy_1; Crank_1; M_Top_1; M_Back_1; LeftSlider2_1; M_Left2_1; RightSlider2_1; M_Right2_1; M_Bottom_1; PAWL_1; base_link; base_link_Shaft_copy_1 (actuator: motor); base_link_M_Bottom_1 (slide); M_Top_1_Crank_1

- 중복 Crank_1(PULLEY_1측, 구 회전29) 완전 제거
-> M_Top_1측 Crank_1(구 회전34) 하나만 남아 트리 구조 확정
- 전 joint명 ParentLink_ChildLink 형식으로 재명명
(한글 조인트명 깨짐 문제 해결, 예: 회전31->base_link_Shaft_copy_1)
- base_link_Shaft_copy_1(메인 샤프트)에 motor actuator 추가
- collision hull(convex hull, 33개)은 현재 비활성화(contype=0)
상태로 대기 중

base_link (root)
fixed joint
continuous + actuator(motor)
continuous (미구동)
prismatic(슬라이더) joint

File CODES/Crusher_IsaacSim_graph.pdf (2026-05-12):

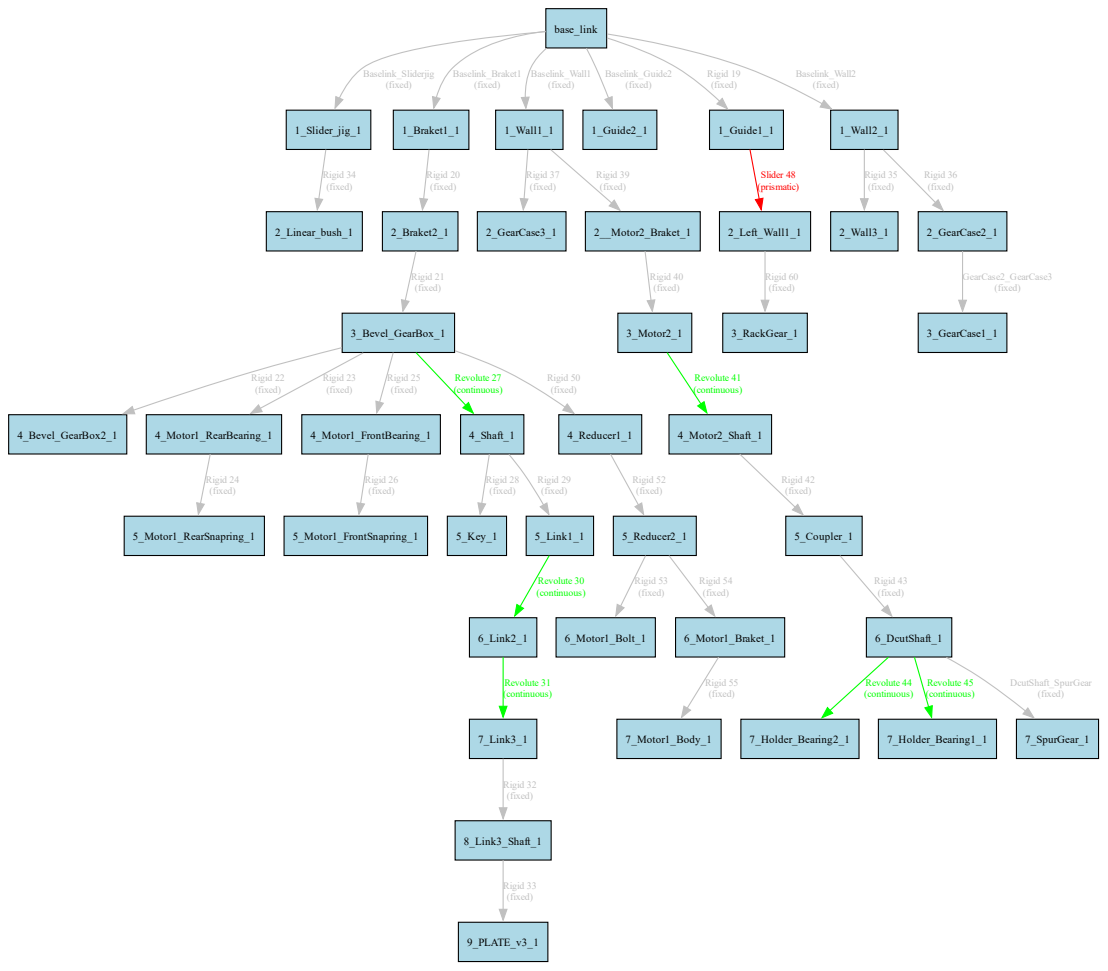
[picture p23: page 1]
base_link; 1_Slider_jig_1; Baselink_Sliderjig (fixed); 1_Braket1_1; Baselink_Braket1 (fixed); 1_Wall1_1; Baselink_Wall1 (fixed); 1_Guide2_1; Baselink_Guide2 (fixed); 1_Guide1_1; Rigid 19 (fixed); 1_Wall2_1; Baselink_Wall2 (fixed); 2_Linear_bush_1; Rigid 34 (fixed); 2_Braket2_1; Rigid 20 (fixed); 2_GearCase3_1; Rigid 37 (fixed); 2__Motor2_Braket_1; Rigid 39 (fixed); 2_Left_Wall1_1; Slider 48 (prismatic); 3_Bevel_GearBox_1; Rigid 21 (fixed); 4_Bevel_GearBox2_1; Rigid 22 (fixed)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

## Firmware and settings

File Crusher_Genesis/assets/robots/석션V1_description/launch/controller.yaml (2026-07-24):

석션V1_controller:
  # Publish all joint states -----------------------------------
  joint_state_controller:
    type: joint_state_controller/JointStateController
    publish_rate: 50

  # Position Controllers --------------------------------------
  슬라이더 2_position_controller:
    type: effort_controllers/JointPositionController
    joint: 슬라이더 2
    pid: {p: 100.0, i: 0.01, d: 10.0}
  슬라이더 11_position_controller:
    type: effort_controllers/JointPositionController
    joint: 슬라이더 11
    pid: {p: 100.0, i: 0.01, d: 10.0}
  슬라이더 12_position_controller:
    type: effort_controllers/JointPositionController
    joint: 슬라이더 12
    pid: {p: 100.0, i: 0.01, d: 10.0}

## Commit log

2026-05-13 Add 20260513 Isaac Sim control scripts and apply CoACD collision
    Scripts (20260513/):
    - Read_USD.py : USD structure reader (links / joints / drive attrs → CSV)
    - Drive_Motor2_ConstVel.py : Pinion revolute joint constant-velocity drive
    - Drive_PrismaticJoint.py : Rack prismatic joint constant-velocity drive
    - CoACD_CollisionFreeOff.py : Selectively enable collision on L2_Left_Wall1_1 (CoACD)
    and L2_Wall3_1 (convexHull)
    - RackAndPinion.py : Rack-and-pinion coupling via physxMimicJoint
    (gearing=-0.0175 m/rad, module=1, teeth=35)
    - Debug_RAP.py : Diagnostic script for PhysxPhysicsRackAndPinionJoint
    U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
    [USD_output.csv]
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2026-05-14 Add MuJoCo migration and Isaac Sim rack-pinion debug scripts
    20260513: Fix Drive_Motor2_ConstVel (velocity unit deg/s, joint limits,
    physics step callback), rewrite RackAndPinion with correct MimicJoint
    direction (on RACK, reference=PINION), add diagnostic/cleanup scripts
    MuJoCo_PlayGround: URDF to MJCF conversion, mujoco_playground viewer
    (CrusherEnv MjxEnv wrapper, mjx-viewer and render_array modes)
    [Collision_output.csv, Crusher_IsaacSim.xml, L1_Braket1_1.stl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]
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2026-05-19 Add tablet STL viewer and collision mesh tools
    - tablets_stl/Codes/: viewer_desktop.py (3-slider PyVista shape viewer),
    collision_viewer.py (convex decomposition with 4 view modes),
    tablet_generator.py (Fusion 360 script for batch STL generation),
    bat launchers and web viewer
    - tablets_stl/stl/_tablet_index.csv: parameter metadata for 1000 tablets
    - .gitignore: exclude STL binaries and Python cache
    - All paths use relative references (__file__-based)
    [_tablet_index.csv]
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2026-05-19 Fix MuJoCo viewer crash in _print_params regex
    CV value captured '0.20.' (including .stl extension) because
    [\d.]+ is greedy. Fix: strip extension with os.path.splitext()
    before regex search. Viewer was crashing before launch() call.
2026-05-19 Add open_crusher_colored.py and fix mujoco.bat paths
    - 20260520/open_crusher_colored.py: opens Crusher_IsaacSim_colored.xml
    (already contains Ground.stl) via mujoco.viewer.launch, __file__-relative path
    - mujoco.bat: replace hardcoded absolute paths with %~dp0-relative MJCF
    path and portable conda activation
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2026-05-20 Fix crank-slider Equality Constraint and add CoACD collision hulls
    Equality Constraint (crank_slider_loop):
    - L8_Link3_Shaft_1 body origin moved to slider pin world pos
    (-0.043302,0.199278,0.049431 → -0.048302,0.236278,0.049431)
    based on URDF Rigid32 joint xyz="0.037 0 -0.005"
    - anchor changed to "0.037 0 -0.005" (slider pin in L7 body-local frame)
    - L8/L9 geom offsets corrected to L8 body frame (subtract slider pin offset)
    - Added damping: L5-L6/L6-L7 hinge=0.5, L8 slide=5
    Viewer (open_crusher_colored.py):
    - Collision hull display OFF by default (visual mesh only)
    - CoACD group=3 hidden by default
    Scripts & assets:
    - patch_collision.py: batch collision property editor
    - run_coacd_le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
    [Crusher_IsaacSim_colored.xml, L2_Left_Wall1_1_hull_000.stl, L2_Left_Wall1_1_hull_001.stl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]
2026-05-21 Fix macOS compatibility in viewer and add tablet STL index
    - viewer_desktop.py: subprocess.CREATE_NEW_CONSOLE → platform 조건부 적용 (macOS 호환)
    - _tablet_index.csv: tablet_generator AddIn으로 정제 STL 1,000개 생성 및 인덱스 갱신
    - README.md: 2026-05-21 변경 이력 추가
    [_tablet_index.csv]
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2026-05-26 Fix xacc → cacc in crank_acceleration.py
    MuJoCo Python bindings expose cacc (com-based spatial acceleration)
    not xacc. cacc[:, 3:6] gives linear acceleration in world frame.
2026-05-26 Add crusher_tablet_sim.py — Crusher + Tablet integrated force sim
    Places a selected tablet STL inside Crusher_IsaacSim_colored.xml at
    (-47.879, 336.199 - thickness/2, 50.108) mm in world frame.
    Tablet orientation: local-Z (thickness axis) aligned to world-Y
    (slider direction) via quat=(0.7071, 0.7071, 0, 0).
    Key design:
    - XML files untouched; combination is done in Python memory via
    xml.etree.ElementTree + from_xml_string(xml, assets={stl_bytes})
    - meshdir set on compiler so Crusher STL refs resolve correctly
    - Force measured via data.cfrc_ext[tablet, 3:6] (contact force,
    world frame) + force site sensor for comparison
    - Real-time console print every 0.1s; two matplotlib plots saved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
2026-05-26 Integrate crusher sim into tablet GUI; fix font warning
    viewer_desktop.py:
    - Add [Crusher 시뮬레이션] button (purple) below existing MuJoCo button
    - _launch_crusher_sim(): calls crusher_tablet_sim.py with current STL
    path via subprocess.Popen (non-blocking, new console on Windows)
    - btn_crusher enabled/disabled alongside btn_mujoco on load success/fail
    crusher_tablet_sim.py:
    - MOTOR_CTRL 5.0 -> 0.5 N*m
    - SIM_DURATION 5.0 -> 10.0 s
    - Replace all Korean matplotlib labels with English to eliminate
    "Glyph missing from DejaVu Sans" UserWarning
2026-05-26 Diagnose weak tablet reaction force: add back_wall, extend sim to 30s, improve force plots
    - Add back_wall geom at WALL_Y+5mm to prevent tablet from flying away on impact
    - SIM_DURATION: 10s → 30s for sufficient crank cycles
    - MOTOR_CTRL: 0.5 N·m (unchanged)
    - run(): track slider_Y and tablet_Y positions in real-time; print gap every 0.5s
    - Detect first contact via cfrc_ext Y > 0.1 N threshold
    - Add cumulative impulse J_Y = ∫F_Y dt plot alongside normal force
    - Save 3 plots: position tracking, normal force + impulse, 3-axis force components
    - All matplotlib labels in English to avoid DejaVu Sans Korean glyph warning
2026-05-26 Remove redundant back_wall injection — L1_Wall1_1 already acts as fixed back wall
    L1_Wall1_1 is a fixed worldbody geom in Crusher XML with default
    contype=1/conaffinity=1, physically located at Y≈WALL_Y_MM (336 mm).
    Tablet is compressed between L8 impact plate and L1_Wall1_1 — no
    separate back_wall box needed.
    - Remove ET.SubElement back_wall block from _build_model()
    - Update docstring, console print, and plot labels to reference L1_Wall1_1
2026-05-27 Fix tablet to wall and enable fixed-position mode in Phase 2
    - Tablet center placed at WALL_Y (336.199 mm) — fully against impact wall
    - Phase 2 now keeps tablet kinematically fixed every step (qpos/qvel overwrite)
    - Remove --fixed flag; fixed mode is now the default behavior
    - Hide site gizmo sphere (sitegroup all False)
    - Refactor to v3: 2-Phase, fixed tablet
2026-05-28 docs: add Crusher + Tablet integrated simulation to README
    - Add quick-start section 5 for crusher_tablet_sim.py
    - Describe 2-Phase workflow, kinematic hold mechanism, and in-memory MJCF build
    - Add 2026-05-27 changelog entry
    - Add 20260527/ directory to structure diagram
    - Add shortcut notice at top of table of contents
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2026-05-28 fix: remove lock_crank equality constraint so motor can drive crank
    lock_crank (polycoef=1.5708, solref=-100000 -1000) was pinning the crank
    at 90° with 100,000 N/rad stiffness — completely overriding the 0.5 N·m motor.
    - Crusher_IsaacSim_colored.xml: delete lock_crank <joint> equality element
    - crusher_tablet_sim.py: also strip lock_crank in _build_model() as a safeguard
    [Crusher_IsaacSim_colored.xml]
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2026-05-28 refactor: replace kinematic hold with mocap body for tablet (v4)
    Kinematic hold (freejoint + qpos overwrite) caused penetration because
    contact separation impulses were discarded every step.
    mocap body approach:
    - body mocap="true": no joint, no nq change, MuJoCo treats it as an
    immovable kinematic wall — collision response is applied to the crusher
    - data.mocap_pos/mocap_quat for position control (no per-step overwrite)
    - Phase 1 loop simplified: no qpos/qvel clobber needed
    Force sensing: cfrc_ext/sensordata → _sum_contact_force()
    - Iterates data.contact, calls mj_contactForce per contact pair
    - Transforms contact frame → world frame via c.frame.reshape(3,3).T
    - Sign corrected whe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
2026-05-28 feat: add floating shortcuts panel (tkinter) alongside MuJoCo viewer
    - _SHORTCUTS table lists all MuJoCo viewer key bindings
    - _show_shortcuts_panel() opens a dark-themed tkinter window in a daemon
    thread so it doesn't block the simulation loop
    - Wireframe toggle (W) highlighted in yellow; section headers in cyan
    - Panel auto-closes with the process; viewer keeps running if panel is closed
    - Opened just before mujoco.viewer.launch_passive()
2026-05-28 feat: normal force plot, crank reversal, and shortcuts panel in tablet viewer
    - Remove tkinter/threading shortcuts panel (wrong location)
    - Add REVERSE_THRESHOLD: detect peak compression (gap > min + 0.5mm) -> reverse crank CW
    - Track motor_on_t, motor_rev_t, min_gap_seen for event markers on plot
    - F_Y plot: label as "Normal Contact Force (World-Y)", add axvline for motor ON / reversal
    - Cumulative impulse plot also shows event markers
    - Add SHORTCUTS panel to left sidebar (PyVista key bindings)
    - Sections: 마우스 / 렌더링(W★) / 카메라 / 기타
    - Styled with dark theme matching existing panel colors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
2026-05-28 fix: replace gap-based reversal with force-based trigger
    Root cause: gap-based reversal (gap > min + 0.5mm) never triggered because
    the mocap tablet blocks the slider dead-stop — gap stays at its minimum
    value indefinitely, so neither the 'if' nor 'elif' branch ever satisfies.
    Fix: trigger crank reversal when |F_Y| > REVERSE_F_THRESHOLD (default 5 N).
    Contact force spikes clearly the moment the slider presses the tablet,
    making it a reliable and physically meaningful reversal signal.
    - Remove min_gap_seen tracking (no longer needed)
    - REVERSE_F_THRESHOLD = 5.0 N (tune as needed)
    - Print: F_Y value and gap at reversal moment
2026-05-28 docs: add 2026-05-28 changelog — mocap tablet, force reversal, shortcuts
    - Update top banner to 2026-05-28
    - Rewrite Section 5 workflow table and core structure to reflect current state
    (mocap body, lock_crank toggle, CCW motor, force-based reversal, vertical quat)
    - Add detailed 2026-05-28 changelog with before/after comparison table,
    explanations for each change, and modified file list
2026-05-29 feat: moving-window stall 역전 + 실시간 반력 플롯 (v5)
    crusher_tablet_sim.py v5 주요 변경:
    [1] Moving-window stall 감지 기반 양방향 크랭크 역전
    - deque(maxlen=30)으로 최신 30스텝 |ω| < 0.05 rad/s 기록
    - 30스텝 모두 stall 시 motor_dir 부호 반전 (CCW ↔ CW 반복)
    - 역전 횟수·시각 콘솔 출력 및 rev_events 리스트로 추적
    - REVERSE_F_THRESHOLD (접촉력 기반 단방향) 제거
    [2] 실시간 법선 반력 플롯 (plt.ion())
    - 시뮬레이터 뷰어와 동시에 F_Y 실시간 창 표시
    - 20 step(0.04 s)마다 line_fy.set_data + flush_events 갱신
    - 방향 전환 axvline 실시간 업데이트
    [3] 크랭크 각속도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
2026-05-29 fix: 알약 Z축 90° 회전 추가 (TAB_QUAT 갱신)
    q_rotZ(90°) ⊗ [0.5, 0.5, 0.5, -0.5] = [√2/2, 0, √2/2, 0]
    (X90° + Y90° + Z90° 3단 합성)
2026-05-29 feat: 실행별 CSV/Plot 자동 저장 (Sim_result/) — v6
    [1] 결과 저장 디렉토리 자동 생성
    - MuJoCo_PlayGround/Sim_result/csv/ ← 반력 프로파일 CSV
    - MuJoCo_PlayGround/Sim_result/plot/ ← 그래프 PNG 5종
    [2] CSV 파일명 = {tablet_stem}__{YYYYMMDD_HHMMSS}.csv
    - 메타데이터 헤더 (# 주석): STL명, R/AR/CV, timestep, 모터 파라미터,
    stall 설정, 배치 좌표, 최대/최소 반력, 임펄스, 방향 전환 이벤트, 첫 접촉 시각
    - 데이터 컬럼: Time_s, F_X/Y/Z_N, F_mag_N, Slider/Tablet_Y_mm,
    Gap_mm, Crank_vel_rad_s, Motor_dir(CCW/CW/off), ncon
    [3] 플롯 파일명 = {tablet_stem}__{YYYYMMDD_HHMMSS}__{tag}.png
    - tags: realt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
2026-05-29 fix: 알약 초기 Y 위치 보정 — 단반경(R_mm)만큼 벽 앞에 배치
    변경 전: pos_y = WALL_Y_MM * 1e-3
    → 알약 중심이 벽면에 위치, 절반이 벽 안에 박힘
    변경 후: pos_y = (WALL_Y_MM - R_mm) * 1e-3
    → 알약 표면이 벽면에 접촉, 중심은 R_mm 앞에 위치
    근거:
    TAB_QUAT = [√2/2, 0, √2/2, 0] 기준 회전행렬 R = [[0,0,1],[0,1,0],[-1,0,0]]
    body-Y(R_mm) → World-Y(압축방향) 이므로 World-Y 반경 = R_mm
    수정 파일:
    crusher_tablet_sim.py: _build_model() pos_y, 배치 출력 메시지
    batch_tablet_sim.py: _build_model(R_mm 파라미터 추가), 호출부 수정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
2026-05-29 refactor: stall 판정을 step수→시간(s) 기반으로 변경 (STALL_TIME_S)
    변경 전: STALL_WINDOW = 30 steps (0.002s × 30 = 0.06s → 방향 전환 너무 빠름)
    변경 후: STALL_TIME_S = 2.0s → stall_window = int(2.0/0.002) = 1000 steps
    - 지긋이 누르는 느낌: 2초 동안 멈춰있어야 방향 전환
    - stall_window = max(1, int(round(STALL_TIME_S / model.opt.timestep)))
    → timestep이 바뀌어도 자동 대응
    - STALL_TIME_S 하나만 수정하면 두 파일 동시 적용
    (crusher_tablet_sim.py, batch_tablet_sim.py)
    조정 가이드:
    0.5s → 빠른 왕복 (테스트)
    2.0s → 지긋이 누르는 느낌 ← 기본값
    5.0s → 장시간 압축 후 후퇴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
2026-05-29 fix: tablet Y-offset를 단반경(R_mm)에서 두께 절반(half_th)으로 변경
    - _build_model 시그니처: R_mm → R_mm + half_th (두 파일 동일)
    - pos_y = (WALL_Y_MM - R_mm) * 1e-3
    → pos_y = (WALL_Y_MM - half_th) * 1e-3
    · half_th = th / 2 where th = R_mm*0.20 + 2*(CV*2*R_mm)
    · 두께 방향(World-Y)으로 절반만 후퇴 → 알약 표면이 벽면에 정확히 접촉
    - crusher_tablet_sim.py: run()에서 half_th 계산 후 _build_model에 전달
    - batch_tablet_sim.py : run_headless()에서 동일 계산 후 _build_model에 전달
    - 관련 주석·docstring·print 메시지 일괄 수정
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2026-06-01 docs: CLI 레퍼런스 섹션 추가 (crusher_tablet_sim / batch_tablet_sim)
    - crusher_tablet_sim.py: 인자 테이블, 4가지 사용 예시, 출력 파일 구조
    - batch_tablet_sim.py: 인자 테이블, 5가지 사용 예시, 출력 구조, summary CSV 컬럼 설명
    - 주요 상수 (SIM_DURATION, MOTOR_CTRL, STALL_TIME_S 등) 조정 가이드 추가
    - 목차에 CLI 레퍼런스 항목 연결
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2026-06-01 chore: 작업 파일 업데이트
    - Crushing_CollisionFree.usd: USD 파일 업데이트
    - open_crusher_colored.py: 컬러 Crusher 뷰어 수정
    - launch_mujoco.py: MuJoCo 실행 스크립트 업데이트
    - check_placement.py: 알약 배치 확인 스크립트 추가
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2026-06-02 fix+feat: np.trapz 호환성 수정, CV 배치 스위프 실험 추가
    - crusher_tablet_sim.py: np.trapz → _np_trapz (NumPy 2.0 AttributeError 수정)
    - viewer_desktop.py: np.hstack faces 배열에 .ravel() 추가 (PyVista dtype 수정)
    - batch_cv_sweep.py: 신규 — CV 10단계 배치 실험 (점접촉 vs 면접촉)
    고정τ / Hertz보정τ 두 모드 비교, 충격량·압력·면적 분석
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2026-06-02 fix: np.trapz AttributeError 완전 수정 (NumPy 2.0)
    getattr(np, 'trapezoid', np.trapz) 패턴은
    Python이 default 인자를 먼저 평가하므로 NumPy 2.0에서 동일하게 터짐.
    → try/except 방식으로 두 파일 모두 교체.
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2026-06-05 Fix Korean font rendering + adapt real motor stall logic to simulation
    Font fix (Malgun Gothic + unicode_minus=False):
    - 20260526/crank_acceleration.py
    - 20260527/batch_cv_sweep.py, batch_tablet_sim.py, crusher_tablet_sim.py
    - 20260603/crusher_tablet_slidejoint.py, run_comparison_headless.py
    Motor control adaptation from Keyborad_control_v2.py:
    - Real motor: rpm_buffer deque(maxlen=5), stall when sum==0,
    set_enable(0) -> direction flip -> time.sleep(0.5) -> set_enable(1)
    - Simulation equivalent applied to crusher_velocity_ctrl.py,
    crusher_tablet_slidejoint.py, batch_cv_sweep.py (20260603):
    * Stall detection via rpm_buf deque (RPM < 1.0 RPM for STALL_TIME_S)
    * Settle period: ctrl=0 f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
2026-06-05 Add wall-tablet contact force measurement to crusher_tablet_slidejoint.py
    - Add _wall_tablet_force_N(): filters L1_Wall1_1 geom ↔ tablet contacts only
    → force6[0] (normal force, always ≥ 0) = actual compressive load
    → equivalent to what a Schleuniger/Erweka hardness tester measures
    - Log f_wall_log[] separately from net contact force
    - Realtime plot now shows F_wall instead of net F_Y
    - Final plot (fig2): 3 subplots — F_wall, net F_Y (ref), cumulative impulse
    - Print F_wall_max (hardness proxy) and J_wall (true impulse > 0)
    - J_net (≈ 0) kept as reference to confirm physics is correct
    No MJCF changes needed — geom ID lookup at runtime.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
2026-06-05 Fix velocity controller vibration: kv 60→3, MOTOR_FORCELIM 120→3
    이전 kv=60 설정은 stall 토크 50 N·m (현실 모터의 ~100배)을 유발해
    접촉 시 과도한 보정 토크 → 속도 오버슈트 → 진동 발생.
    kv=3으로 낮추면 stall 토크 ≈ 2.5 N·m (소형 모터 수준),
    안정 조건 kv×dt/J_eff < 2 를 만족하여 8 RPM 매끄럽게 추종.
2026-06-05 Update docstring to reflect kv=3, FORCELIM=3 defaults
    주석/docstring 에 남아있던 이전 값(kv=60, 120 N·m) 참조를
    실제 수정된 값(kv=3, 3 N·m)으로 일치시킴.
2026-06-05 Add real motor specs (BL4281+212:1) and quasi-static inertia injection
    [모터 파라미터 실측 기반 재산정]
    - MOTOR_STALL_TORQ=0.185 N·m, GEAR_RATIO=212, MOTOR_INERTIA_KG=72e-7 kg·m²
    - CRANK_R_M=0.02 m, ROD_L_M=0.08 m
    - 실측 F≈625N, r=0.02m → τ_stall_crank=12.5 N·m (감속기 효율 ~32%)
    - VEL_KV_DEFAULT = 14.9 (= τ_stall / ω_target)
    - MOTOR_FORCELIM = 12.5 N·m
    [준정적 조건 — 환산 관성 주입]
    - _build_model()에서 L4_Shaft_1 inertia에 J_motor×n²=0.324 kg·m² 추가
    - 없으면: kv·dt/J_crank = 2121 >> 2 → 수치 발산
    - 있으면: kv·dt/J_eff = 0.092 << 2 → 완전 안정 ✓
    [예측 슬라이더 힘 (stall)]
    - θ=90°: 625 N (실측 600-6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
2026-06-08 Add simulation results and .gitignore
    - Add .gitignore: exclude .claude/, TabletCrusher/ (separate repo), __pycache__
    - Add Sim_result/csv: velocity ctrl and slide joint raw data (6 files)
    - Add Sim_result/cv_sweep: CV sweep results - CSV + PNG (2 runs, 20260605)
    - Add Sim_result/debug: headless diagnostic PNG (implicitfast fix verification)
    - Add Sim_result/plot: per-run result plots (velctrl + slidejoint)
    - Add Sim_result/tdp_test: TDP verification plots (R4.0, CV0.08/0.20)
    [cv_sweep_20260605_104350.csv, cv_sweep_20260605_125807.csv, slidejoint_tablet_R4.0_AR1.00_CV0.08__20260605_141042.csv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]
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2026-06-10 Improve velocity ctrl: stall dwell, hard contacts, crank angle plot
    - Add STALL_DWELL_S=3s: hold at stall before reversing (prevents oscillation)
    - Add COOLDOWN_S=2s: disable stall detection after direction flip
    - Hard tablet contact: solref=0.001 2, solimp=0.99 0.999 0.001, margin=1mm
    - Reduce timestep to 0.001s for penetration prevention
    - condim 4->3, remove density-based soft contact (remove _density_tau)
    - Add crank angle [deg] as twin-y axis on RPM subplot (realtime + final figure)
    - Simplify subplots to RPM-only and F_Y-only (remove torque from plots)
    - Remove stale Sim_result cv_sweep output files
    [cv_sweep_20260602_165133.csv, cv_sweep_20260605_104350.csv, cv_sweep_20260605_125807.csv]
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2026-06-19 Add Genesis PBD envelope sims + M0609/RG2 grasp & box pick-move
    - Genesis 1.1.0 (Metal) headless PBD medicine-envelope sims:
    particle distribution, box-drop cohesion/containment
    - M0609 (Doosan) MJCF + OnRobot RG2 gripper (Panda-style slide
    fingers + equality constraint), mounted on link_6 flange
    - Grasp & lift via fix_particles_to_link (orientation-preserving
    vertical lift, S=j2+j3+j5 fixed); camera tracking
    - Box-in-bag pick-and-move on aluminum plate floor
    - Twin.md: equality constraint, weld timing, primitive vs mesh
    collision, custom-entity techniques
    - Ignore generated Sim_result/ outputs and .codegraph cache
    [MF0609_0_0.stl, MF0609_1_0.stl, MF0609_2_0.stl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]
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2026-07-06 sim strike 프로파일 성형 + 반력플롯 정리 + 슬라이더/plate 렌더 + viewer 영문·무채색화
    - Crusher_8env: sim strike 를 needle→사다리꼴(stall dwell + 접촉 1차지연)로 성형,
    peak(Fpk) 보존. compare/overlay 플롯 갱신. DigitalTwin.md §6-2 노트 반영
    - plot_reaction_profiles: 흰 배경 + 10분(600s) 크롭
    - Crusher_only: HIDE_LEFT_WALL + SLIDER_VIEW(impact plate 포커스) 렌더 추가
    - make_slider_montage: 각도별 슬라이더 2×3 라벨 몽타주 빌더
    - viewer_desktop: 한글 UI 전부 영문화 + 컬러 액센트 전부 무채색화
    - 결과 아티팩트(몽타주·프레임·플롯) 및 M0609 에셋 등 추적 시작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
    [crusher_samplebag_open.stl, m0609.urdf, m0609.urdf.xacro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]
2026-07-06 IPC 커플러 GPU 검증 + 로봇↔FEM-cloth 컨택 최소 테스트
    - Genesis 1.2.1 dev-mode 전제 하에 GPU(sm_120)에서 IPCCouplerOptions
    + M0609+RG2(articulated rigid) + FEM.Cloth 봉투가 crash 없이 build·step 확인
    (기존 cudaErrorInvalidDevice 재현 안 됨). 핑거 close 시 IPC 접촉으로 천 7.2mm 변형.
    - ipc_grasp_bag_test.py: 중력 OFF, 봉투 띄워 순수 접촉 관찰 (contact-check 진단 포함).
    - 발견: IPC는 PBD 미지원(fem+rigid만 등록), FEM set_vertex_constraints 는
    IPC 커플러에서 차단(fem_entity.py:907) → Crushing 파지(fix_particles_to_link weld)
    직접 이식 불가. RG2 gap(~46mm)로 얇은 봉투 pinch 불가 → 파지 기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
    [_ipc_test_bag.stl]
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2026-07-08 경로 중앙화(config.json+paths.py) + assets/ 재편 + IPC 마찰 파지 원인 3건 규명
    - assets/: MJCF/, robots/ 를 assets/ 하위로 이동 (git rename, 경로 원장 config.json 신설)
    - paths.py: config.json 로더 — 스크립트는 paths.* 상수만 사용 (위치 독립 부트스트랩)
    - 정식 셋 6+1 + FEM/ipc + 20260603 아카이브 경로 마이그레이션 (전부 실행 검증)
    - legacy/: medicine_envelope_* 등 이전 세션 잔재 9개 격리
    - PROJECT_NOTES: 구조도+경로 규약(§2), Genesis 인용 BibTeX(§9)
    - IPC 파지 테스트: 무접촉 원인 3건 규명·수정
    1) IPC 커플러에 FEM vertex constraint 미배선 → 마찰 파지로 전환 (선반+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
    [Crusher_IsaacSim.xml, Crusher_IsaacSim_colored.xml, Ground.stl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]
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2026-07-12 OnRobot RG2 실물충실 MJCF(m0609_rg2_v2.xml) + M0609_RG2 테스트 스위트 신설
    - 공식 STL/URDF(ikalevatykh/onrobot_ros, MIT)로 moment_arm/truss_arm/
    finger_tip mimic 구조 재구성 — 4-bar 폐루프 대신 <equality><joint> 근사
    - joint range 재교정 오류 발견·수정: 한때 [0.8229,1.8751](flex_finger 몸체
    원점 기준, 비단조)로 잘못 바꿨던 걸 원래 yaml 값 [0,1.3]으로 원복 — pad
    mesh 중심 기준 실측하니 0→112mm(열림)~1.3mm(닫힘) 단조 확인
    - 수치발산 버그 수정: finger 링크 diaginertia 1e-6→1e-4 + integrator
    implicitfast (velocity actuator+<equality> 조합이 기본 Euler 에서 발산)
    - flex_finger CoACD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
    [body.stl, finger_tip.stl, finger_tip_1.stl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]
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2026-07-13 M0609+RG2 IPC 봉투 실링부 마찰 파지 + box 그립 안정화 + FEM 낙하 버그 발견
    - grasp_box_test.py: control_dofs_position 통합 호출(팔+그리퍼 12DOF 한 번에),
    noslip_iterations=20 + constraint_timeconst=0.005 로 정지 시 접촉 소실 문제
    해결, decimate=True+smooth=True 렌더 개선.
    - grasp_bag_test.py(신규, PBD): 핑거 mesh 접촉 시 즉시 폭발 — IPC 전환 필요성
    문서화.
    - grasp_bag_ipc_test.py(신규): IPC 커플러 + FEM.Cloth 로 실측 STL 대신
    procedural 프록시(자기충돌 회피, D=6mm) 봉투의 실링 가장자리를 v2(6DOF
    mimic) 그리퍼로 마찰 파지·리프트(slip <0.2mm). 손목 90도 회전으로 그리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
    [Samplebag desigin.stl, Samplebag_seal_pouch3.stl]
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2026-07-20 고정장치(fixture jig) URDF→MJCF 변환 자산 추가 + full_workflow.py에 배치
    fusion2urdf 출력(고정장치_description)의 URDF를 flatten 후 mujoco로 MJCF
    컴파일. 나머지 부품(base_link/L1/Back/R1/F1/MotorDriver/T1/Servo1~3/
    ServoShaft)은 전부 contype=0/conaffinity=0(충돌 없음)이고, 실제로 뭔가를
    붙잡는 Jig_1만 CoACD 64-hull 볼록분해로 충돌을 켰다. 그 덕에 Servo3_
    ServoShaft(continuous) 회전 조인트도 self-intersection 오탐 없이 원본 그대로
    유지. full_workflow.py에 로봇/Crusher/슬롯 작업구역과 안 겹치는 플레이트 위
    (0.5,-0.3,0.12)에 static 소품으로 배치(two_way_soft_constraint).
    [16-631-1.stl, 7901A5TYN Ball.stl, 7901A5TYN Inner ring.stl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]
2026-07-21 고정장치/M0609 렌더링 스파이크 수정 + 회수장치2 자산 추가 + fusion2urdf 관성 반올림 버그 수정 + FEM 봉투-정제 드랍 실험
    - 고정장치/M0609 메시 22개: trimesh smooth_shaded로 하드엣지 스무딩(볼트머리 등
    작은 디테일에서 나던 스파이크 아티팩트 해결), 고정장치 바디 검정/지그 은색 색상 적용
    - fusion2urdf/URDF_Exporter/utils.py: origin2center_of_mass의 round(x,6)이
    소형 부품(너트/베어링 등, 관성 ~1e-7 이하) 관성을 0으로 뭉개던 버그 수정
    (round(x,12)로 정밀도 상향) — 향후 export부터 적용
    - assets/robots/회수장치2_description 신규 추가(원본 URDF, 아직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
    [Back_1_ss.obj, Bearing1_1.stl, C-SSRY20200_b.stl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]
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2026-07-27 고정장치+회수장치2 조립 및 석션V1 미믹/충돌 마무리
    - 고정장치: T1/L1/R1 CoACD 볼록분해 추가. 기존 Jig_1_hull_* 포함 전체 hull
    mesh에 scale=0.001 누락 버그 발견·수정(1000배 오버사이즈로 충돌이 사실상
    한번도 제대로 작동한 적 없었음). T1과 Jig_1은 CAD상 원래 맞닿아있어 둘 다
    충돌 켜면 IPC build가 죽어(8가지 조합 격리 테스트로 확인) T1은 시각 전용으로
    되돌리고 L1/R1/Jig만 충돌 유지.
    - 회수장치2: 고정장치 ServoShaft 정렬점에 위치 정렬(X,Y,Z) 후 Jig 스윕과
    겹치는 문제를 Z+25mm로 해소(0/64 오버랩, CLI로 전체 회전 사이클 검증).
    G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
    [Adjust_Plate_01_1_ss.obj, Dummy_1_ss.obj, GPL0601_1_ss.obj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]
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2026-08-18 recovery2_mjcf 로 시뮬레이터 참조 전환 + 시각 메시 스파이크 전처리
    full_workflow.py(따라서 full_workflow_rigid.py 도) / Recovery2_only 3종 /
    Fixture_only 스택 2종이 보던 회수장치2_description(fusion2urdf→URDF→MJCF) 를
    fusion2xml 직행 빌드 recovery2_mjcf/recovery2.xml 로 옮긴다.
    **두 빌드는 모델 원점이 다르다.** 두 XML 을 MuJoCo qpos0 로 올려 부품 33개의
    메시 월드 AABB 를 대조한 결과, 구 빌드는 자기 샤프트 힌지축이 정렬 기준점
    (Fusion 조인트 앵커 -74.015, 59.22)에서 (+30.92, -6.62, 0)mm 어긋나 있었고 신
    빌드는 0.01mm 안에서 일치한다. 그래서 RECOVERY2_POS 는 그대로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
    [Bearing1_1_ss.obj, Crank_1_ss.obj, F_Back_1_ss.obj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]
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
